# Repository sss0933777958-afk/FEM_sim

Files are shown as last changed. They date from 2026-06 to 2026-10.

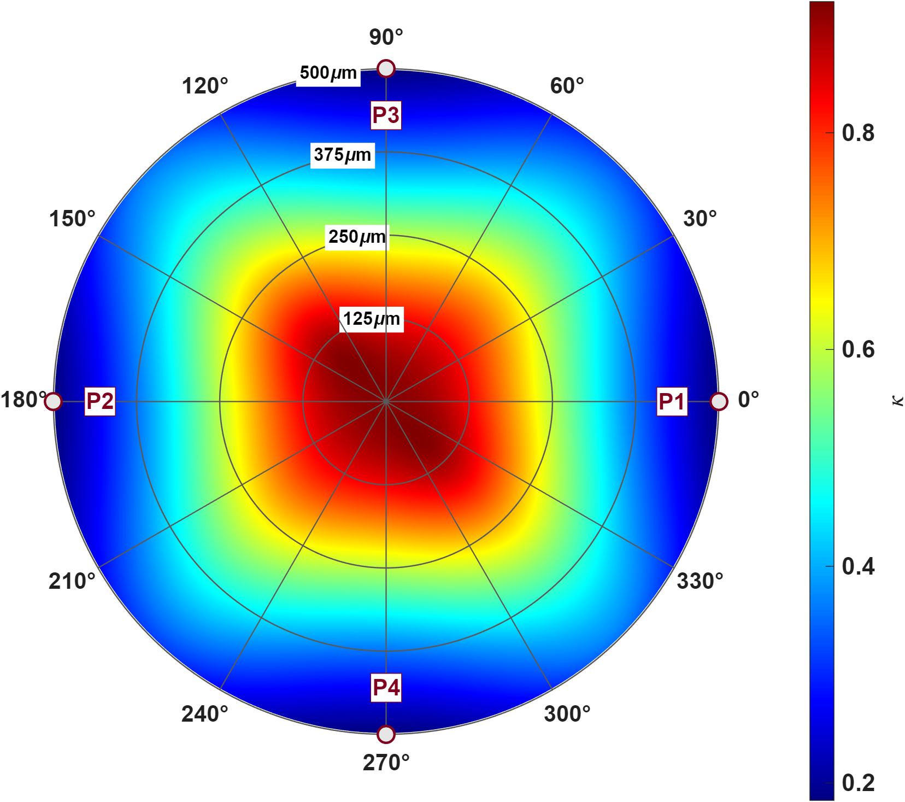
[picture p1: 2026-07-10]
magnetic_sim/ANSYS/main/matlab/Flux/APDL/Calibration_using_FEM_modeling/figures/hung_hexapole/current/common/iso_polar_xaya.png

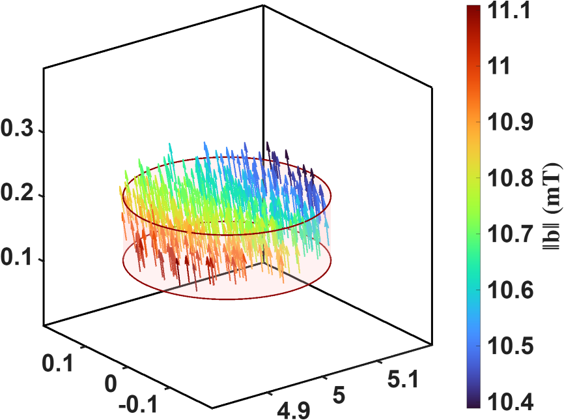
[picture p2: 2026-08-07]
magnetic_sim/ANSYS/main/figures/paper_fig/Section3_A/圖片1.png

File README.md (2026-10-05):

# FEM_sim

六極電磁微探針（hexapole magnetic tweezers）的 FEM 模擬與點磁荷模型校正。

- 求解器：ANSYS MAPDL（APDL）、ANSYS Maxwell
- 分析：MATLAB
- 模型：長飛 2016 半切六極（主力）、志鵬平板六極、hung、NTU

## 資料夾

```
magnetic_sim/ANSYS/
├── main/                    活躍工作區
│   ├── CAD_model/           SolidWorks 原檔 + STEP（幾何的依據）
│   ├── model_check/         交付檢查用的 mm STEP
│   ├── apdl/<model>/        APDL 腳本
│   ├── ANSYS_data/<model>/  APDL 結果（.dat、.db，不進 git）
│   ├── matlab/
│   │   ├── Flux/            磁場模型校正（APDL / Maxwell 兩個分支）
│   │   └── Force/           力模型校正
│   ├── figures/             論文圖
│   └── reference/           推導、報告、論文
└── backup/                  歸檔的舊設計
```

Maxwell 專案與匯出的場（`.fld`）放在 repo 外：`D:\Maxwell_sim\<model>\`。

## 校正包的結構

以 `matlab/Flux/Maxwell/` 為例（Force 沒有自己的 `config/`，共用這裡的）：

| 資料夾 | 放什麼 |
|---|---|
| `config/` | 各模型的設定與幾何 |
| `main/main.m` | 校正主程式，改檔頂的參數切換模型與 current / voltage |
| `function/` | 校正用函式 |
| `data/` | 校正結果 `.mat`（只留定案版） |
| `results/` | 校正結果 PDF |
| `utils/scripts/<model>/`、`utils/data/<model>/` | 額外分析的計算腳本與結果（依模型分夾） |
| `plot/` | 只做繪圖的腳本 |
| `figures/<model>/{current,voltage}/` | 圖 |

## 怎麼跑

```matlab
run('magnetic_sim/ANSYS/main/matlab/Flux/Maxwell/main/main.m')   % 磁場校正
run('magnetic_sim/ANSYS/main/matlab/Force/Maxwell/main/main.m')  % 力模型校正
```

跑完會自動存 `.mat` 到 `data/`、出 PDF 到 `results/`。

## 環境

- ANSYS 2025 R2（MAPDL、Maxwell）
- MATLAB R2025b

## 參考

Fei Long, *Design, Fabrication, and Calibration of a Hexapole Magnetic Tweezers*, PhD Dissertation, Ohio State University, 2016.

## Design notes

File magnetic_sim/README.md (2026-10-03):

# magnetic_sim/ — 磁學模擬類別

**用途**：`FEM_sim/` 下的磁學（magnetostatic / eddy-current）模擬類別，收磁鑷 hexapole / quadrupole 相關工作。目前是 `FEM_sim/` 唯一的物理類別；未來其他 FEM 類別（靜電 / 結構 / 熱）會與本夾**並列**為兄弟資料夾。

**內容**：依**求解器**分子層：
- `ANSYS/` — ANSYS MAPDL 求解器子層（含 `main/` 活躍設計 + `backup/` 歸檔）。
- `COMSOL/` — COMSOL 求解器子層（與 ANSYS/ 並列），目前存 `.mph` 模型。

**相關**：repo 總覽見 `../CLAUDE.md` / `../README.md`；ANSYS 活躍設計導覽見 `../CLAUDE.md`。

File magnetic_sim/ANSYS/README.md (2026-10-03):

# magnetic_sim/ANSYS/ — ANSYS 求解器子層

**用途**：磁學模擬中以 ANSYS MAPDL（APDL magnetostatic FEM）求解的部分。分活躍設計與歸檔兩層。

**內容**：
- `main/` — ★ 目前唯一活躍設計：4-pole MEMS Quadrupole（原 `kuo/`）。完整 pipeline（CAD → IGES → APDL → ANSYS_data → matlab → MATLAB_data → doc）；各子夾有自己的 README。
- `backup/` — 歸檔（非活躍）設計：`hexapole-long2016/`、`hung/`。

**相關**：工作目錄全域規則見 `../../CLAUDE.md`（含資料夾架構地圖 + 產物落點）與 `../../.claude/rules/`；流程 SOP 見 `main/reference/workflows/`；歸檔說明見 `backup/README.md`；COMSOL 部分見 `../COMSOL/README.md`。

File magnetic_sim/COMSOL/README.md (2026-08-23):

# magnetic_sim/COMSOL/ — COMSOL 求解器子層

**用途**：磁學模擬中以 COMSOL Multiphysics 求解的部分，與 `../ANSYS/` 並列為同一磁學類別下的另一求解器。

**內容**：
- `mph/` — COMSOL `.mph` 模型，依 model topic 分子夾（`kuo_quadrupole/`、`long2016_hexapole_halfcut/`）。

**相關**：上層磁學類別見 `../README.md`；COMSOL LiveLink headless 連線通用法見 `../ANSYS/main/reference/workflows/comsol-livelink.md`（拆兩 process + `mphstart(2036)`）；各 model 模型清單見 `mph/README.md`。

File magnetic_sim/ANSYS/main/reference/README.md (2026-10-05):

# reference/ — 文件（LaTeX 推導 / 報告）+ 流程 SOP + 論文 PDF

技術推導、報告 LaTeX 原稿與編譯 PDF，以及 Claude 可 follow 的跨主題流程 SOP。

## 結構
```
reference/
├── workflows/                ← ★ 流程 SOP（cad-export / apdl-fem-run / charge-model-fit / …）
│                               入口見 workflows/README.md
├── Question/                 ← 待討論 / 待辦的研究問題（每題一份 .md）
├── charge_model_fitting/     ← 電荷模型擬合推導（fitting_derivation / general / <model>/）
├── Solve_B_matrix/<model>/   ← B_S 矩陣推導
├── Br_analysis/<model>/      ← Br 分析
├── pole_WP_distance/<model>/ ← pole–WP 距離
├── fitting_trend/scripts/    ← R 掃描趨勢
├── error_definition/{pdf,scripts}
├── magenetic_flux_integral/{pdf,scripts}
└── ur_iteration/{pdf,scripts}
```

## 檔案類型
- `*.tex`（原稿）/ `*.pdf`（編譯產物）/ `*.m`（LaTeX 表格產生器）/ `*.md`（SOP、說明）。

## 規則
- **跑流程 / 操作前先看 `workflows/README.md`** 找對應 SOP（自然語觸發對照也在該 README）。
- LaTeX 原稿放 `<analysis>/<topic>/scripts/`，編譯 PDF 放 `<analysis>/<topic>/pdf/`（analysis-first schema）。
- 中文報告需要圖時 **reference** `../matlab/<model>/<功能組>/figures/<file>.png`，不要把圖另存到 git root 外。

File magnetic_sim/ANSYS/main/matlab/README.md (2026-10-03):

# matlab/ — MATLAB 分析程式碼

讀 FEM 場（APDL `.dat` / Maxwell `.fld`）做點電荷模型擬合、解轉移矩陣、出結果 PDF。

## 第一層 = **求解器分支**（不是 model）

```
matlab/
├── APDL/       ← MAPDL（純量位）求解的場
│   └── Calibration_using_FEM_modeling/   ← 三模型共用校正管線（有自己的 README，權威）
└── Maxwell/    ← Ansys Maxwell 求解的場（結構鏡像上者，但少一層 Calibration 夾）
```

兩分支的 `function/` 是**鏡像**（同檔名、同職責、只差讀檔那一支：`extract_ansys_data` vs
`extract_maxwell_data`）。**改動要兩邊同步**——尤其 `emit_results.m`、`build_V_matrix.m`、
`utils/pole_sensor_geometry.m`。

> 兩分支對同一顆 long2016 模型有 **~14% 的 ĝ_I 落差**（9.66 vs 10.75 mT/A），已排除材料 / 幾何 /
> 安匝 / 網格收斂，尚未結案。比較兩邊數字前先確認基準一致（同 variant、同 R、同 dataset）。

## 共用結構（兩分支皆同）

```
config/<model>/[<geom>/]mt_constants.m   幾何 + 物理常數 + 路由旗標（唯一常數來源）
function/                                管線函式庫（見各分支 function/README.md）
main/main.m                              driver：只改頂部 per-run 旗標
utils/pole_sensor_geometry.m             ★ sensor 貼附幾何**唯一來源**（CAD 實測錐體 + 0.41mm 氣隙）
utils/<model>/                           後處理 compute 腳本（讀 calib .mat → 算 → 存 computed .mat）
plot/<model>/<base>/                     繪圖腳本（讀 .mat → 出圖，不重運算）
data/<model>/.mat/                       所有 .mat（自描述：結果 + 產生它的設定）
results/<model>/{single,eighteen}/        結果 PDF（single=USE_BIAS false、eighteen=true）
figures/<model>/<base>/{single,eighteen,common}/   圖檔
common_path/ansys_path.m                 路徑 resolver（model-agnostic）
```

三段式分工（不可越界）：
**① 校正** `main/main.m` + `function/` → `data/.../calib_*.mat`
→ **② compute** `utils/<model>/` 讀 calib `.mat` → 存 computed `.mat`（**不重跑校正**）
→ **③ 畫圖** `plot/<model>/<base>/` 讀 `.mat` → `figures/`（**不做重運算**）

## 跑法

```matlab
% 改 main.m 頂部旗標即可切換，其餘不用動
MODEL='long2016_hexapole_halfcut'; GEOM='tip40um';
VARIANT='maxwell';        % APDL 分支用 'graded'
BASE='voltage';           % 'current' | 'voltage'
USE_BIAS=true;            % false=single(fix) / true=eighteen(18-param bias)
R_select=150e-6;          % 定案取樣半徑
```
跑完自動存 `.mat` 並呼叫 `emit_results` 出 PDF。

## 產物落點（規則）

- `.mat` → `data/<model>/.mat/`（**不要**再寫 `MATLAB_data/`，該夾 2026-06-26 已移除；
  `matlab_path()` resolver 已 deprecated）。
- PDF → `results/<model>/{single,eighteen}/`，**只放 `.pdf`**（`.tex/.aux/.log` 由 emit 端編完即刪）。
- 圖 → `figures/<model>/<base>/{single,eighteen,common}/`。
- ⚠ **論文圖不在這裡**：`figures/paper_fig_plot/{plot,data}` → `figures/paper_fig/Section*/`。

## 規則（動手前先讀全文）

- **禁止使用 `backup/` 的資料與程式**（`no-backup-data.md`）——常數一律 `model_config(model, geom)`。
- 全程 **actuator frame**（`actuator-frame.md`）、**all-source 號誌**（`charge-model-source-convention.md`）。
- **coil→paper map 是 per-model 不可互抄**（`pole-coil-numbering.md`）；驗證看 K̄_I 對角占優且全正。
- 擬合電流必須 = FEM 激發電流 1 A（`fit-current-matches-sim.md`）。
- 結構凍結：新增 / 改名 / 移動 / 刪除檔或夾**一律先問**（`calibration-shared-structure.md`）。
- 單位：ℓ̂ µm、場 mT、ĝ_I mT/A、ĝ_V mT/mV、V mV（`unit-reference.md`）。

## 相關

`APDL/Calibration_using_FEM_modeling/README.md`（管線總覽）、同夾 `function/README.md`（逐函式速查）、
`../../../../CLAUDE.md`（資料夾架構地圖）、`../ANSYS_data/<model>/RESULTS_MAP.md`（讀結果前必查）。

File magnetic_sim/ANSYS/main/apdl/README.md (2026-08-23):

# apdl/ — APDL 腳本（FEM 的 input）

ANSYS MAPDL 的幾何 / 模擬 / 後處理腳本。這是**重跑 sim 的 input**，改參數/幾何/mesh 都在這裡改。

## 結構：`<model>/{geom,sim,postproc}/`
```
apdl/
├── long2016_hexapole_halfcut/  {geom, sim, postproc}
├── kuo_quadrupole/             {geom, sim, postproc}
└── zhang_quadrupole/           {geom, sim, postproc}
```
- `geom/` — `MT_Geom*.txt` 幾何建模（含 IGES 匯出腳本）。
- `sim/` — `MT_Sim_*.txt` / 各 coil 求解腳本（含 baseline / 變體 / mesh）。
- `postproc/` — 抽場 / dump / PATH 等後處理腳本。

## 檔案類型
- `*.txt` — APDL 腳本（純文字 input）。
- `*.py` — 產生/轉換 APDL 的輔助腳本。

## 規則
- 改動標 `[ADDED]` / `[MODIFIED]`（English comments），見 `.claude/rules/apdl-editing.md`。
- 多 coil 腳本**只差 `CURR_ARRAY`**，其餘同步；`D,ALL,MAG,0` 邊界必存在。
- 改幾何尺寸前對齊 CAD（`ansys-cad-alignment.md`）。
- 跑 FEM / 後處理 SOP：`reference/workflows/{apdl-fem-run,apdl-postproc}.md`。
- 解出來的結果存到 `../ANSYS_data/<model>/<case>/`。

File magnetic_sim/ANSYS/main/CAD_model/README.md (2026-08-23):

# CAD_model/ — SolidWorks / STEP 原始幾何

幾何的 **source of truth**。所有 ANSYS 幾何尺寸必須對齊這裡（見 `.claude/rules/ansys-cad-alignment.md`）。

## 結構：`<topic>/{SLDPRT,STEP}/`

```
CAD_model/
├── kuo_quadrupole/   {SLDPRT, STEP}
├── long_fei/         {SLDPRT, STEP}   ← 注意：此處 topic 名用 long_fei
└── zhang_quadrupole/ {SLDPRT, STEP}
```

> ⚠ 命名不一致：CAD 這裡用 `long_fei`，但 `ANSYS_data/`、`IGES/`、`apdl/` 用 `long2016_hexapole_halfcut`。指同一個物理模型。

## 檔案類型
- `*.SLDPRT` / `*.SLDASM` — SolidWorks 原檔（可編輯的母檔）。
- `*.STEP` — 中性格式匯出（解析尺寸、跨軟體交換）。

## 規則
- 改 ANSYS 幾何 / `mt_constants` 前**必先量對應 CAD**，不一致須通報使用者拍板（per `ansys-cad-alignment.md`）。
- 出 STEP/IGES 流程：`reference/workflows/cad-export.md`。
- STEP 抽參數做參數表：`reference/workflows/step-to-apdl.md`。

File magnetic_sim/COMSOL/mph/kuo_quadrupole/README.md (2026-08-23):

# magnetic_sim/COMSOL/mph/kuo_quadrupole/ — Kuo Quadrupole COMSOL 模型

**用途**：Kuo 4-pole MEMS Quadrupole 的 COMSOL `.mph` 模型（建模迭代 + baseline + 求解版本）。

**內容**（實際 `.mph`）：
- `quadrupole_new.mph` — 目前主用大模型（含解，~360 MB；mphinterp/mpheval 座標用 **mm**，見 memory）。
- `quadrupole_new_split.mph` — 拆分版（精簡）。
- `0.46mm_baseline.mph` — L_P=0.46 mm baseline。
- `tweezer.mph` — 較早的整體 tweezer 模型。
- `monolithic_T55.mph` 及 `quadrupole_*_T55.mph` 系列（imported / with_air / with_coils / with_blocks / with_physics / solved / solved_blocks）— T=55 µm 漸進建模各階段。

**相關**：上層 model 索引見 `../README.md`；LiveLink 連線見 `../../../ANSYS/main/reference/workflows/comsol-livelink.md`；mm 座標探測坑見 memory `feedback_comsol_mm_coord_pitfall`；ANSYS 對應設計見 `../../../ANSYS/main/`。

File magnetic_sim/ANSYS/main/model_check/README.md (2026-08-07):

# model_check/ — 模型檢查交付夾（STEP 主、legacy IGES）

**用途**：ANSYS 建完的幾何**交付使用者疊 CAD/SolidWorks 檢查**的檔案放這裡。
（2026-07-11 由 `IGES_converted/` 改名而來；原「單位轉換後給 ANSYS `IGESIN`」用途已 vestigial——`IGESIN` 2025R2 已棄用，CAD 匯入改走 STEP→SpaceClaim→`ac4para`→`.db`。）

## 🔒 交付一律出 STEP（規則 `deliver-step-for-check.md`）
- **檢查交付檔＝`.step`**（`SI_UNIT(.MILLI.,.METRE.)` 明確 mm，SolidWorks/OCC 讀對）。
- **不要交付 ANSYS `IGESOUT` 的 `.iges`**：被 SolidWorks/OCC **讀成英吋 ×25.4**（板厚 0.25→6.35mm），IGES units flag 6→2 + name `2HMM` **都救不了**。
- STEP 產法：OCC（OCP）讀原始 STEP solid + primitive 實體 compound + `write.step.unit=MM`；範本 `apdl/<model>/geom/scripts/make_*_step.py`。

## 結構：`<model>/`
```
model_check/
├── NTU_hexapole/     pole_assembly.step (交付檢查) + pole*.iges (legacy)
├── long_fei/         *.iges (legacy)
└── hung_hexapole/    *.iges (legacy)
```

## 檔案類型
- `*.step` — **交付檢查用**（mm、SolidWorks 讀對）。
- `*.iges` — legacy（ANSYS IGESOUT 出的、SW 讀成 ×25.4，**勿再交付**，僅留存）。

## 相關
- 規則 `.claude/rules/deliver-step-for-check.md`（交付一律 STEP）。貼 `model_check/<model>/*` 路徑時直接從第二層認模型（`long_fei` / `hung_hexapole` / `NTU_hexapole`），不必問。
- backup/hung 有自己的 `backup/hung/IGES_converted/`（**未改名**，另一設計）。

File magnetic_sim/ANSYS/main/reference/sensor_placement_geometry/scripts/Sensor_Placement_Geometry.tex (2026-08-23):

\documentclass[12pt]{article}
\usepackage[T1]{fontenc}
\usepackage{mathptmx}
\usepackage{amsmath}
\usepackage{amssymb}
\usepackage{array}
\usepackage{booktabs}
\usepackage[a4paper,top=1.6cm,bottom=1.6cm,left=2.3cm,right=2.3cm]{geometry}
\setlength{\parindent}{0pt}
\setlength{\parskip}{4pt}

\newcommand{\ehat}[1]{\mathbf{e}_{#1}}
\newcommand{\rhat}{\hat{\mathbf{r}}}
\newcommand{\that}{\hat{\mathbf{t}}}
\newcommand{\nhat}{\hat{\mathbf{n}}}
\newcommand{\dir}{\operatorname{dir}}

\begin{document}

\begin{center}
\large\textbf{Hall-Sensor Placement Geometry on a Conical Pole}\\[2pt]
\normalsize Derivation of $\;\mathbf{p}=\mathbf{T}+s_{\mathrm{ax}}\ehat{2}+R(s_{\mathrm{ax}})\,\rhat+a\,\ehat{3}$
\end{center}

\vspace{2pt}
\hrule
\vspace{8pt}

\textbf{Scope.} This note derives the closed-form construction used by
\texttt{utils/pole\_sensor\_geometry.m}, which is the single source of truth for the
six Hall-sensor centres $\mathbf{p}_i$ and their outward normals $\nhat_i^{+}$.
All vectors are expressed in the WP frame (origin at the common sphere centre of the
six pole tips) in metres. The construction is per-pole; the index $i$ is dropped.

\section{Direction convention}

Every direction below is written with the elevation--azimuth helper
\begin{equation}
\dir(\varepsilon,\theta)=
\begin{bmatrix}\cos\varepsilon\cos\theta\\ \cos\varepsilon\sin\theta\\ \sin\varepsilon\end{bmatrix},
\qquad
\dir(\varepsilon,\theta)\cdot\dir(\varepsilon',\theta)=\cos(\varepsilon-\varepsilon').
\label{eq:dir}
\end{equation}
The second identity is the only algebra needed to check orthogonality inside a
meridian plane: two directions sharing the azimuth $\theta$ are orthogonal iff their
elevations differ by $90^\circ$.

Per-pole inputs: azimuth $\theta$ (pole angles $0,180,120,300,60,240^\circ$ for
$P_1\ldots P_6$) and the layer flag (lower / upper).

\section{Pole tip and pole axis}

\textbf{Tip.} The six tips lie on a sphere of radius $\ell=R_{\mathrm{norm}}$. The
magic-angle elevation follows from the locked hexapole constraints
$R_{\mathrm{norm},xy}=\ell\sqrt{2/3}$, $R_{\mathrm{norm},z}=\ell/\sqrt{3}$:
\begin{equation}
\psi_0=\arctan\!\frac{R_{\mathrm{norm},z}}{R_{\mathrm{norm},xy}}
      =\arctan\frac{1}{\sqrt2}=35.2644^\circ ,
\qquad
\ehat{1}=\dir\!\big(\sigma_\ell\psi_0,\ \theta\big),\qquad
\mathbf{T}=\ell\,\ehat{1},
\label{eq:tip}
\end{equation}
with $\sigma_\ell=-1$ for a lower pole and $+1$ for an upper pole.

\textbf{Axis.} The cone axis $\ehat{2}$ points from the tip \emph{towards the base}
(direction of increasing axial station $s$):
\begin{equation}
\ehat{2}=\dir(\varepsilon,\theta),\qquad
\varepsilon=\begin{cases}
0 & \text{lower pole (horizontal axis)}\\
\varepsilon_{\mathrm{up}}=36.5895^\circ & \text{upper pole}.
\end{cases}
\label{eq:axis}
\end{equation}

\textbf{Remark (do not confuse $\ehat{1}$ with $\ehat{2}$).} The tip direction and the
pole axis are \emph{different} vectors. For a lower pole $\ehat{1}$ has elevation
$-35.2644^\circ$ while $\ehat{2}$ is horizontal; for an upper pole the elevations are
$+35.2644^\circ$ and $+36.5895^\circ$. Only $\ehat{1}$ carries the magic angle --- it is
fixed by the orthogonality/common-sphere constraints. The axis inclination
$\varepsilon_{\mathrm{up}}$ is the physical tilt of the machined pole and is an
independent number.

\section{The local triad and the radial vector \boldmath$\rhat$}

This is the part that is easy to forget. Fix a pole. Two more unit vectors are built
so that $\{\ehat{2},\rhat_0,\that\}$ is orthonormal:
\begin{align}
\rhat_0 &= \dir\!\big(\varepsilon+\sigma\,90^\circ,\ \theta\big),
  &&\sigma=\begin{cases}-1 & \text{lower pole}\\ +1 & \text{upper pole}\end{cases}
  \label{eq:rad0}\\[2pt]
\that &= \begin{bmatrix}-\sin\theta\\ \cos\theta\\ 0\end{bmatrix}.
  \label{eq:tanv}
\end{align}

\textbf{Why these are orthonormal.} $\ehat{2}$ and $\rhat_0$ share the azimuth
$\theta$ and their elevations differ by exactly $90^\circ$, so
$\ehat{2}\cdot\rhat_0=\cos(\mp90^\circ)=0$ by \eqref{eq:dir}. The vector $\that$ is
horizontal and perpendicular to the azimuthal direction
$[\cos\theta,\sin\theta,0]^{\mathsf T}$, hence perpendicular to \emph{any}
$\dir(\cdot,\theta)$; in particular $\that\perp\ehat{2}$ and $\that\perp\rhat_0$.

\textbf{Geometric meaning.}
\begin{itemize}\itemsep2pt
\item $\ehat{2},\rhat_0$ span the \emph{meridian plane} --- the vertical plane
      containing the pole axis (azimuth $\theta$). $\rhat_0$ is the radial direction
      inside that plane, pointing away from the axis.
\item The sign $\sigma$ selects \emph{which side} of the axis the sensor is mounted on.
      A lower pole is the half-cut part: the mounting face is its \textbf{bottom} cone
      surface, so $\sigma=-1$ tilts $\rhat_0$ downwards. An upper pole is a full cone
      and is mounted on the upper side, so $\sigma=+1$.
\item $\that$ is tangential --- perpendicular to the meridian plane. It is only needed
      to rotate the mounting point around the pole axis.
\end{itemize}

\textbf{Azimuthal placement around the axis.} Rotating $\rhat_0$ about $\ehat{2}$ by an
angle $\psi$ stays in the plane spanned by $\rhat_0$ and $\that$ (both are
perpendicular to $\ehat{2}$), so Rodrigues' formula collapses to
\begin{equation}
\boxed{\ \rhat(\psi)=\cos\psi\;\rhat_0+\sin\psi\;\that\ }
\label{eq:rhat}
\end{equation}
with $\rhat(\psi)\perp\ehat{2}$ and $\|\rhat(\psi)\|=1$ for all $\psi$. The canonical
sensor azimuth is $\psi=0$, i.e. $\rhat=\rhat_0$, which places the sensor in the
meridian plane --- directly below (lower) or above (upper) the pole axis.

\textbf{Caveat on the sense of rotation.} A direct evaluation of the cross product
gives $\ehat{2}\times\rhat_0=-\sigma\,\that$. Therefore \eqref{eq:rhat} is a
right-handed rotation about $\ehat{2}$ by $-\sigma\psi$: the sense of increasing $\psi$
is opposite between the two layers. This is immaterial at the default $\psi=0$ and for
symmetric sweeps, but it must be kept in mind if a signed azimuthal offset is ever
imposed.

\section{The real cone: virtual apex, radius, and outward normal}

\subsection{Virtual apex}

The pole is not a mathematically sharp cone: the tip is rounded with a fillet of
radius $r_f=40\ \mu$m, and the conical surface is \emph{tangent} to that sphere. Let
$\beta$ be the true half-cone angle. For a sphere of radius $r_f$ inscribed tangentially
in a cone of half-angle $\beta$, the distance from the apex to the sphere centre is
$r_f/\sin\beta$. Placing the sphere centre at axial station $s=r_f$ (so that the
foremost point of the sphere --- the physical tip $\mathbf{T}$ --- sits at $s=0$), the
apex lies \emph{outside} the material at
\begin{equation}
s=-e_v,\qquad
\boxed{\ e_v=\frac{r_f}{\sin\beta}-r_f\ }\;\approx\;0.16\ \mathrm{mm}.
\label{eq:apex}
\end{equation}

\subsection{Cone radius}

Measuring the axial station $s$ from the physical tip, the distance from the virtual
apex is $e_v+s$, so
\begin{equation}
R(s)=(e_v+s)\tan\beta,
\qquad
R(0)=e_v\tan\beta\approx 0.033\ \mathrm{mm}\neq 0 .
\label{eq:radius}
\end{equation}
The non-zero intercept is the whole point: \textbf{at the axial position of the tip the
cone surface already has a finite radius}. Anchoring the mounting point at the ideal
tip with $R=0$ is what used to push the sensor into the steel (Sec.~\ref{sec:old}).

\subsection{Outward normal}

Parametrise the cone surface by $(s,\psi)$:
\begin{equation}
\mathbf{P}(s,\psi)=\mathbf{T}+s\,\ehat{2}+R(s)\,\rhat(\psi).
\end{equation}
The generator (slant) direction is
\begin{equation}
\hat{\mathbf{g}}
=\frac{\partial\mathbf{P}/\partial s}{\|\partial\mathbf{P}/\partial s\|}
=\frac{\ehat{2}+\tan\beta\,\rhat}{\sqrt{1+\tan^2\beta}}
=\cos\beta\,\ehat{2}+\sin\beta\,\rhat .
\label{eq:gen}
\end{equation}
The surface normal lies in the meridian-like plane $\mathrm{span}\{\ehat{2},\rhat\}$,
is perpendicular to $\hat{\mathbf{g}}$, and must point away from the axis
($\nhat\cdot\rhat>0$). The unique unit vector satisfying all three is
\begin{equation}
\boxed{\ \ehat{3}\;=\;\nhat^{+}\;=\;\cos\beta\,\rhat-\sin\beta\,\ehat{2}\ }
\label{eq:normal}
\end{equation}
since $\hat{\mathbf{g}}\cdot\ehat{3}=\cos\beta\sin\beta-\sin\beta\cos\beta=0$ and
$\ehat{3}\cdot\rhat=\cos\beta>0$. At $\psi=0$ this is exactly
$\dir\!\big(\varepsilon+\sigma(\beta+90^\circ),\theta\big)$, i.e. the axis direction
rotated by $\sigma(90^\circ+\beta)$ inside the meridian plane.

\section{Axial station from the slant offset}

$\mathrm{SOFF}$ is defined as the \textbf{slant distance measured along the generator},
starting from the ``red point'' --- the point of the generator at the same axial station
as the tip, i.e. $(s,R)=(0,\,e_v\tan\beta)$. Advancing a slant distance
$\mathrm{SOFF}$ along $\hat{\mathbf{g}}$ advances the axial station by its $\ehat{2}$
component, hence
\begin{equation}
\boxed{\ s_{\mathrm{ax}}=\mathrm{SOFF}\cdot\cos\beta\ }
\label{eq:sax}
\end{equation}
with the design value $\mathrm{SOFF}=4.572$~mm ($=0.18$~inch).

\textbf{Convention.} Quoting a mounting offset always means the \emph{full} slant
distance measured in the meridian plane, \emph{including} its leading segment: saying
``$\mathrm{SOFF}=4$~mm'' already contains the portion $t_{\tan}$ that is pressed
against the fillet rather than the cone, and the whole $4$~mm is then projected onto
the axis by $\cos\beta$. The CAD-measured fillet segments are $t_{\tan}=0.0328$~mm
(lower) and $0.0311$~mm (upper); they are recorded only for drawing the pole outline
and do \emph{not} enter \eqref{eq:sax}.

\textbf{History.} An earlier revision used
$s_{\mathrm{ax}}=(\mathrm{SOFF}-t_{\tan})\cos\beta+t_{\tan}$, which measured
$\mathrm{SOFF}$ from the physical tip and treated the leading segment as purely
axial. The two differ by $t_{\tan}(1-\cos\beta)\approx0.6\ \mu$m, three orders of
magnitude below the air gap, so no downstream result changed.

\section{Assembly}

Stacking \eqref{eq:tip}, \eqref{eq:sax}, \eqref{eq:radius}, \eqref{eq:rhat} and
\eqref{eq:normal}, and lifting the sensor off the surface by the air gap
$a=0.41$~mm along the outward normal:
\begin{equation}
\boxed{\;
\mathbf{p}
=\underbrace{\mathbf{T}}_{\text{tip}}
+\underbrace{s_{\mathrm{ax}}\,\ehat{2}}_{\text{slide along axis}}
+\underbrace{R(s_{\mathrm{ax}})\,\rhat(\psi)}_{\text{out to the cone surface}}
+\underbrace{a\,\ehat{3}}_{\text{lift off the surface}}\;}
\label{eq:assembly}
\end{equation}

Read left to right, the four terms are: start at the pole tip; slide along the axis to
the correct axial station; step radially outwards until you reach the actual cone
surface at that station; then lift perpendicular to that surface by the air gap.
Because the last step uses the true surface normal \eqref{eq:normal}, the perpendicular
distance from the sensor centre to the cone surface is \emph{exactly} $a$ by
construction.

\subsection*{Degenerate case: flat mounting face}

For the lower pole the option \texttt{face\_lower='flat'} mounts the sensor on the
half-cut plane instead of the bottom cone. That plane \emph{contains} the pole axis,
so there is no radial stand-off and no slant projection:
\begin{equation}
s_{\mathrm{ax}}=\mathrm{SOFF},\qquad R=0,\qquad \nhat^{+}=\hat{\mathbf{z}},
\qquad \mathbf{p}=\mathbf{T}+\mathrm{SOFF}\,\ehat{2}+a\,\hat{\mathbf{z}} .
\end{equation}
The azimuth $\psi$ has no meaning for a plane and is ignored.

\section{Numerical values (long2016 half-cut, CAD-measured cone)}
\label{sec:num}

$\ell=0.5$~mm, $r_f=0.04$~mm, $\mathrm{SOFF}=4.572$~mm, $a=0.41$~mm.
The two layers have \emph{different} measured cone slopes
($\tan\beta=0.20330$ lower, $0.19463$ upper; a $4.4\%$ difference).

\begin{center}
\begin{tabular}{lccccc}
\toprule
Layer & $\beta$ [deg] & $e_v$ [mm] & $s_{\mathrm{ax}}$ [mm] & $R(s_{\mathrm{ax}})$ [mm] & poles \\
\midrule
Lower & 11.4916 & 0.16078 & 4.48035 & 0.94354 & $P_1,P_3,P_6$ \\
Upper & 11.0138 & 0.16937 & 4.48779 & 0.90642 & $P_2,P_4,P_5$ \\
\bottomrule
\end{tabular}
\end{center}

Spot check for $P_1$ ($\theta=0$, lower, $\psi=0$): $\ehat{2}=[1,0,0]^{\mathsf T}$,
$\rhat_0=\dir(-90^\circ,0)=[0,0,-1]^{\mathsf T}$, so \eqref{eq:normal} gives
\[
\nhat^{+}=\cos\beta\,[0,0,-1]^{\mathsf T}-\sin\beta\,[1,0,0]^{\mathsf T}
=[-0.1992,\ 0,\ -0.9800]^{\mathsf T},
\]
which is what the code returns. The normal tilts $\beta$ away from straight-down,
as it must for a surface whose generator is inclined by $\beta$ to the axis.

\section{Why the naive construction fails}
\label{sec:old}

A tempting shortcut is to anchor at the ideal tip and walk the slant distance directly:
$\mathbf{p}=\mathbf{T}+\mathrm{SOFF}\cdot\dir(\varepsilon+\sigma\beta,\theta)+a\,\ehat{3}$.
This ignores the finite radius $R(0)=e_v\tan\beta\approx0.033$~mm at the tip station,
so the mounting point is placed \emph{inside} the steel. The resulting perpendicular
distance to the \emph{real} cone surface is
\[
0.3635\ \mathrm{mm}\ \text{(lower)},\qquad 0.4012\ \mathrm{mm}\ \text{(upper)},
\]
instead of the specified $0.41$~mm --- an $11\%$ error on the lower poles, and
inconsistent between layers. The construction \eqref{eq:assembly} removes both defects:
the stand-off is exactly $a$ on every pole.

\vspace{6pt}
\hrule
\vspace{4pt}
{\footnotesize
\textbf{Implementation:} \texttt{matlab/Maxwell/utils/pole\_sensor\_geometry.m}
(and the identical copy under \texttt{matlab/APDL/Calibration\_using\_FEM\_modeling/utils/}).
Consumers: \texttt{build\_V\_matrix.m} and every script that draws sensors or pole
outlines --- none of them may re-derive this geometry locally.\par
\textbf{Related:} \texttt{.claude/rules/ansys-cad-alignment.md} (CAD is the source of
truth); memory \texttt{long2016-pole-cone-geometry} (STEP measurements and how they
were taken).}

\end{document}

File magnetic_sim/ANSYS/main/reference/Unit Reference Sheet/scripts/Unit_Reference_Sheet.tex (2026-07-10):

\documentclass[12pt]{article}
\usepackage[T1]{fontenc}
\usepackage{mathptmx}
\usepackage{amsmath}
\usepackage{amssymb}
\usepackage{array}
\usepackage[a4paper,top=1.5cm,bottom=1.5cm,left=2.3cm,right=2.3cm]{geometry}
\setlength{\parindent}{0pt}

\begin{document}

\begin{center}
\large\textbf{Lumped-Parameter Modeling and Calibration of Hexapole\\
Electromagnetic Actuators for Magnetic Flux Generation}
\end{center}

\vspace{6pt}

\textbf{Current Base Model}
\[
b(p) = \underbrace{\left(\tfrac{6}{5}k_{11}\right)\left(\frac{N_c}{4\pi\,\widehat{\ell}^{\,2}\,R_a}\right)}_{\textstyle {}^{B}\widehat{g}_{I}}\; S_i\,\overline{K}_{I}\,I
= S_i\Big(\underbrace{{}^{B}\widehat{g}_{I}\,\overline{K}_{I}\,I}_{\textstyle G}\Big)
\]

\vspace{10pt}

\textbf{Voltage Base Model}
\[
b(p) = S_i\cdot D\cdot V
= S_i\cdot\Big[\underbrace{\left(\tfrac{6\,d_{11}}{5}\right)}_{\textstyle {}^{B}\widehat{g}_{V}}\overline{D}\,V\Big]
= S_i\Big(\underbrace{{}^{B}\widehat{g}_{V}\,\overline{D}\,V}_{\textstyle G}\Big)
\]

\vspace{8pt}

\begin{center}
\renewcommand{\arraystretch}{2.6}
\begin{tabular}{>{\centering\arraybackslash}m{6.0cm} | >{\centering\arraybackslash}m{4.5cm}}
\multicolumn{1}{c|}{\textbf{Symbol}} & \multicolumn{1}{c}{\textbf{Unit}} \\[2pt]
\hline
$R_a$ & $\dfrac{A}{Wb}$ \\
\hline
$I$ & $A$ \\
\hline
${}^{B}\widehat{g}_{I}$ & $\dfrac{mT}{A}$ \\
\hline
${}^{B}\widehat{g}_{V}$ & $\dfrac{mT}{mV}$ \\
\hline
$V$ & $mV$ \\
\hline
$\widehat{\ell}$ & $\mu m$ \\
\hline
$b(p)$ & $mT$ \\
\hline
$\left(\dfrac{3V}{\mu_0}\right)\!\left(\dfrac{\mu-\mu_0}{\mu+2\mu_0}\right) \triangleq {}^{M}\widehat{g}_{B}$ & $\dfrac{\mathbf{m}}{mT}$ \\
\hline
$\left(\dfrac{{}^{M}\widehat{g}_{B}}{2\widehat{\ell}}\right)\!\left({}^{B}\widehat{g}_{I}\right)^{2} \triangleq {}^{F}\widehat{g}_{I}$ & $\dfrac{pN}{A^{2}}$ \\
\hline
$\left(\dfrac{{}^{M}\widehat{g}_{B}}{2\widehat{\ell}}\right)\!\left({}^{B}\widehat{g}_{V}\right)^{2} \triangleq {}^{F}\widehat{g}_{V}$ & $\dfrac{pN}{mV^{2}}$ \\
\hline
$\mathbf{m}(p) \triangleq {}^{M}\widehat{g}_{B}\cdot b(p)$ & $A\cdot \mu m^{2}$ \\
\hline
$\begin{cases} k_m = \dfrac{\mu_0}{4\pi} = 10^{-7} \\[6pt] \mu_0 = 4\pi\cdot 10^{-7} = 0.0013\cdot 10^{-3} \end{cases}$ & $\dfrac{pN}{A^{2}}$ \\
\hline
\end{tabular}
\end{center}

\end{document}

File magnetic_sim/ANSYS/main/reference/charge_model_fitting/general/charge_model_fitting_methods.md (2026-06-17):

# 磁荷模型擬合：三種方法詳解 [A] / [J] / [B-6x]

> **文件目的**：詳細寫出 Long Fei dissertation Section 2.2.3 「6-charge magnetic field model」三種等級擬合方法的**完整推導過程 + 演算法步驟 + MATLAB code + 數值範例**。
>
> **適用對象**：要重做 fit、要 reproduce 結果、要寫論文 methodology 章節的人。
>
> **最後更新**：2026-06-03

---

## 目錄

- [0. 為什麼要 fit + 龍飛 b=0 假設](#0-為什麼要-fit-磁荷模型)
- [1. 三方法共用的數學工具與資料前處理](#1-三方法共用基礎)
- [2. Method [A] — 共用 ell 球面擬合（2 參數）](#2-method-a--共用-ell-球面擬合2-參數)
- [3. Method [J] — 6-coil joint 自由 3D 擬合（24 參數）](#3-method-j--6-coil-joint-自由-3d-擬合24-參數)
- [4. Method [B-6x] — ell+δ 全激勵擬合（19 參數）★ 定案](#4-method-b-6x--ellδ-全激勵擬合19-參數--定案)
- [5. 三方法對比與何時用哪個](#5-三方法對比)
- [6. 對龍飛 b=0 假設的回饋](#6-對龍飛-b0-假設的回饋)
- [7. 腳本/數據/圖檔清單](#7-腳本資料圖檔清單)
- [8. 名詞速查](#8-名詞速查)

---

## 0. 為什麼要 fit 磁荷模型？

### 0.1 出發點

Long Fei dissertation Eq 2.2 把 6 顆 pole 的 B 場 model 寫成 6 個**等效點電荷** (point charges)：

```
        ⎛   6                                     ⎞
B(p) = ⎜  Σ   k_m · q_i / |p − c_i|² · u_i(p, c_i) ⎟
        ⎝ i=1                                     ⎠
```

其中：
- `q_i` = 第 i 顆 pole 的等效磁荷（[A·m]）
- `c_i` = 第 i 顆磁荷的位置（[m]）
- `k_m = μ₀/(4π) = 10⁻⁷ N/A²`

每顆 charge 有 1 個 **scalar** 強度 q_i 跟 3 個 **位置** (x_i, y_i, z_i)。總計 6×4 = 24 自由度。

### 0.2 龍飛的兩個 fit 假設

論文 page 18-20 fit 出 (ρ, R_a) = (900 µm, 6.3×10⁸ A/Wb)。
他**暗藏**兩個假設：

1. **位置假設**：所有 charge 都坐在半徑 ρ 的球面上，方位由 pole tip 幾何決定 → **b_i ≡ 0**（每顆 charge 沒有額外偏移）
2. **強度假設**：6 顆 charge 強度由 K_I 矩陣 + R_a 決定，**只剩 R_a 是 free 參數**

→ 自由度從原本 24 砍到剩 **2** (ρ, R_a)。

### 0.3 三種方法的定位

我們做的三種 fit 是 **逐步放鬆龍飛的兩個假設**：

| Method | 自由度 | 放鬆什麼 | 數據量 | 主要目的 |
|---|---|---|---|---|
| **[A]** | **2** | 完全照龍飛 (b=0 + 球面) | 1 coil (P1) | reproduce Long Fei，提供 ρ baseline |
| **[J]** | **24** | 放開到全自由 (18 dim bias + 6 個獨立 C) | 6 coils | 量化 b≠0 偏離有多大 |
| **[B-6x]** | **19** | ρ 鎖定 + 自由 δ + 共用 1 個 C ★定案 | all6 superposition | 物理上最一致 + 數值最準 |

下面三章逐一**完整**推導。

---

## 1. 三方法共用基礎

### 1.1 統一的 fit 方程（被擬合的物理 model）

**從 Long Fei Eq 2.1-2.4 一路推到 fit 用的形式**：

#### Step A：原始物理 model（Eq 2.2）

```
            6                  p − c_i
B(p) =  Σ   k_m · q_i · ──────────────────
           i=1            |p − c_i|³
```

- **k_m = μ₀/(4π) = 10⁻⁷ N/A²**（磁 Coulomb 常數，跟靜電 Coulomb 1/(4πε₀) 對應）
- q_i = 第 i 顆 charge 強度 [A·m]

#### Step B：把電流→磁荷（Eq 2.1 + 2.4）

```
q_i = Φ_i / μ₀ = -(N_c / (μ₀ · R_a)) · (K_I · I_vec)_i = -(N_c/(μ₀·R_a)) · w_i
```

代回 Step A：

```
            ⎛   N_c       ⎞   6                p − c_i
B(p) = -k_m·⎜ ──────────  ⎟ · Σ   w_i · ──────────────────
            ⎝ μ₀ · R_a   ⎠  i=1          |p − c_i|³
       └──────────────────┘
       這整坨叫做「振幅 ξ」
```

#### Step C：合併成 fit-friendly 形式

```
            ⎛  6                p − c_i             ⎞
B_model(p; θ) = ξ · ⎜  Σ   w_i · ──────────────────  ⎟       ← fit 用形式
            ⎝ i=1               |p − c_i|³             ⎠

其中  ξ = -k_m · N_c / (μ₀ · R_a)
     = 振幅因子（合併 k_m 跟所有物理常數）
```

| 變數 | 意義 | 在三方法中的角色 |
|---|---|---|
| **ξ** | 全局振幅 = -k_m · N_c/(μ₀·R_a) | 解析解（VarPro），所有方法都這樣處理 |
| **k_m** | 磁 Coulomb 常數 = μ₀/(4π) = 10⁻⁷ N/A² | 物理常數，吸收進 ξ |
| **N_c** | 每極線圈匝數 = 70 | 物理常數，吸收進 ξ |
| **μ₀** | 真空磁導率 = 4π×10⁻⁷ T·m/A | 物理常數 |
| **R_a** | 集總空氣磁阻 [A/Wb] | 唯一 free 物理量，從 ξ 反推 |
| **w_i** | 第 i 顆 charge 的相對權重 = (K_I · I_vec)_i | 固定（由激勵電流決定） |
| **c_i** | 第 i 顆 charge 的 3D 位置 | **三方法差別就在這怎麼參數化** |
| **p** | 場點位置 [m] | FEM 節點座標 |

#### Step D：從 ξ 反推 R_a

fit 完拿到 ξ 後：

```
            k_m · N_c
R_a = ─────────────────────
          μ₀ · |ξ|
```

（負號 cancel；取 |ξ| 是因為 SOURC36 繞線方向給的符號 convention，per `coil_sign`）

> **注意**：在 MATLAB code 裡（per `point_charge_model.m`），習慣把 ξ 拆成兩部分：
> - 「外層 C」= N_c/(μ₀·R_a) ← 對應 `R_a_unit = N_c/μ₀` 讓 C=1 的 trick
> - 「內層 k_m」 baked into b_unit（因為 `point_charge_model` 函式內部已乘 k_m）
> 兩種 convention 數學等價，本文檔之後用 ξ 統一表示「整坨振幅」。

### 1.2 統一的 cost function

```
              N    
J(θ) = Σ Σ  ‖ B_model(p_j; θ) − B_FEM(p_j) ‖²       ← 向量 L² norm
        j=1
              ↑                ↑
       647 個 FEM 節點    對應 3 個分量 (Bx, By, Bz)
```

→ residual 是 **3N = 1941 維向量**（647 node × 3 component），用 `fminsearch` / `fminbnd` 最小化。

### 1.3 Variable Projection (VarPro) — 把 ξ 消掉

關鍵觀察：**B_model 對 ξ 是線性**（位置決定方向，ξ 只是振幅）。

定義 `b_geom(θ_geom) = Σᵢ wᵢ · (p − cᵢ)/|p − cᵢ|³`（純幾何 basis，不含 k_m 或 R_a）：

```
B_model(p; θ) = ξ · b_geom(p; θ_geom)

J(ξ, θ_geom) = ‖ ξ · b_geom(θ_geom) − b_FEM ‖²
```

對 ξ 求導 = 0 解析：

```
            b_geom^T · b_FEM
ξ_opt = ─────────────────────
            b_geom^T · b_geom
```

→ **不用數值搜尋 ξ**，每次只搜尋 θ_geom，每個 θ_geom 都直接代公式算 ξ_opt。Reduced cost：

```
                            (b_geom^T · b_FEM)²
J*(θ_geom) = ‖b_FEM‖² −  ─────────────────────
                              b_geom^T · b_geom
```

從 ξ_opt 回推 R_a：

```
R_a = k_m · N_c / (μ₀ · |ξ_opt|)
```

**Method [A] / [J] / [B-6x] 都用這個 trick**。
（在 code 裡 b_unit 已含 k_m，所以分兩階段：先算 C_opt 再算 R_a，數學等價於這裡的 ξ_opt。）

### 1.4 K_I 磁通分佈矩陣

當激勵 Coil k（i.e., 通 1A 到 pole k 的線圈），6 顆 charge 的權重：

```
w = K_I · I_vec,    K_I = I₆ − (1/6) · 1₆ = ⎡ 5/6  −1/6  ⋯  −1/6 ⎤
                                              ⎢ ⋮              ⋮  ⎥
                                              ⎣ −1/6 ⋯       5/6 ⎦
```

例：激勵 P1 (`I_vec = [1,0,0,0,0,0]ᵀ`) → `w = [5/6, −1/6, −1/6, −1/6, −1/6, −1/6]ᵀ`

- 主極 P1 得 **5/6** 權重（dominant、flux sink）
- 其餘 5 顆各得 **−1/6**（passive、flux source）
- 總和 = 0（磁通守恆，div B = 0）

### 1.5 資料前處理鏈（共用）

```
ANSYS FEM (V4 halfcut baseline, 6 coils × 0.6A) 
    ↓ 載入 coord + bfield .dat → 390k nodes
    ↓ 鐵芯節點排除 (geometric cone filter) → 341k nodes
    ↓ 取 WP 中心 100 µm cube |x|,|y|,|z_wp| < 50 µm → 647 nodes
    ↓ 座標轉換 z_wp = z_apdl − SPH_OFST (SPH_OFST = −12.711 mm)
    ↓ B 場分量堆疊
b_FEM = [bx; by; bz] (1941 × 1)
```

### 1.6 物理常數 + 幾何常數（從 `mt_constants.m`）

**物理常數**：

| 符號 | 數值 | 意義 |
|---|---|---|
| **μ₀** | 4π×10⁻⁷ T·m/A | 真空磁導率 |
| **k_m** | μ₀/(4π) = **10⁻⁷ N/A²** | 磁 Coulomb 常數（dissertation page 18 標 `km = μ₀ = 1.0×10⁻⁷ N/A²`，跟 `μ₀/4π` 等價）|
| **N_c** | 70 | 每極線圈匝數（dissertation page 14）|

**幾何常數**：

```
R_norm    = 500 µm           WP 到極尖物理距離
R_norm_xy = R_norm·√(2/3) = 408 µm
R_norm_z  = R_norm/√3 = 289 µm
α         = arctan √2 = 54.74°   極角
SPH_OFST  = −12.711 mm        APDL → WP 座標 z 平移
```

6 極方位角 (paper 索引)：
- Lower (P1, P3, P6): θ = 0°, 120°, 240°，z_sign = −1
- Upper (P2, P4, P5): θ = 180°, 300°, 60°，z_sign = +1

APDL index → paper index 映射：APDL `{1,2,3,4,5,6}` = Paper `{P1, P3, P6, P5, P2, P4}`。

---

## 2. Method [A] — 共用 ell 球面擬合（2 參數）

**腳本**：`magnetic_sim/ANSYS/backup/hexapole-long2016/analysis/fit_charge_model.m`
**輸出**：`data/charge_model_fit.mat`
**主結果**：ell = 835.4 µm, R_a = 9.21×10⁸ A/Wb, mean err 4.94%

### 2.1 假設（完全照搬龍飛）

- 6 顆 charge 全部坐在半徑 ell 的球面上
- 方位由 pole tip 幾何完全鎖死
- 6 顆共用同一個 ell
- 共用同一個 R_a（即同一個 C）
- 只用 1 個 coil (P1, APDL coil 1) 的數據

### 2.2 數學參數化

charge 位置：

```
c_i = ell · d̂_i,   i = 1..6

d̂_i = [cos θ_i · sin α,  sin θ_i · sin α,  z_sign_i · cos α]
```

α = 54.74° 固定。θ_i 跟 z_sign_i 由 paper 幾何完全決定。

驗證：|c_i| = ell·√(sin²α + cos²α) = ell ✓

**自由變數總計 = 2 個**：
- ell ∈ [400, 2000] µm（位置，數值搜尋）
- C → R_a（VarPro 解析）

### 2.3 演算法詳細步驟

```
Step 0: 載入資料
    d = import_ansys_data('coil1', 'all', 'coil1')
    把 (x, y, z) 轉到 WP 座標系: z_wp = z − SPH_OFST
    應用鐵芯過濾 → 341k nodes
    取 100 µm cube → 647 nodes
    b_FEM = [bx; by; bz]   ← 1941×1

Step 1: 設定 K_I 跟 I_vec
    K_I = I₆ − (1/6)·1₆
    APDL coil 1 → paper P1, 所以 I_vec = [1, 0, 0, 0, 0, 0]ᵀ (paper 順序)
    w = K_I · I_vec = [5/6, −1/6, −1/6, −1/6, −1/6, −1/6]ᵀ
    
    coil_sign = +1 (P1 是 lower, SOURC36 繞線方向給 sink)

Step 2: Phase 1 — ell 粗掃
    For ell ∈ linspace(400e-6, 2000e-6, 300):
        c_i = ell · d̂_i,  i = 1..6
        對每個 FEM 節點 p_j 算 b_unit_j = Σᵢ w_i · (p_j − c_i)/|p_j − c_i|³
        b_unit_vec = [b_unit_x; b_unit_y; b_unit_z]  ← 1941×1
        C_opt(ell) = (b_unit_vec' · b_FEM) / (b_unit_vec' · b_unit_vec)
        cost(ell) = ‖ C_opt · b_unit_vec − b_FEM ‖²
    
    ell_0 = argmin cost(ell)

Step 3: Phase 2 — fminbnd 精煉
    ell* = fminbnd(@(ell) ell_cost(ell, p_FEM, b_FEM, w),
                   ell_0 − 200e-6, ell_0 + 200e-6,
                   optimset('TolX', 1e-12))

Step 4: 取最後 C_opt 並回推 R_a
    [b_unit*, ~] = compute_unit_field(ell*, w, p_FEM)
    C_opt* = (b_unit*' · b_FEM) / (b_unit*' · b_unit*)
    R_a = N_c / (μ₀ · |C_opt*|)
    
Step 5: 報告誤差
    B_pred = C_opt* · b_unit*
    residual = B_pred − b_FEM
    err_per_node = ‖residual_j‖ / ‖B_FEM_j‖    對每個節點
    mean_err = mean(err_per_node)
    max_err = max(err_per_node)
```

### 2.4 MATLAB code 骨架

```matlab
% --- fit_ell_cost.m (核心 cost function) ---
function [cost, C_opt] = fit_ell_cost(ell, p_wp, b_fem, w, K_I, c)
    % Build 6 charge positions
    d_hat = build_d_hat(c);              % 6×3 方向矩陣
    charges = ell * d_hat;               % 6×3 位置矩陣
    
    % Build unit field
    R_a_unit = c.N_c / c.mu_0;           % 讓 C=1
    [bx, by, bz] = point_charge_model(p_wp, ell, R_a_unit, ...
                                       I_vec, K_I, c);
    b_unit = [bx; by; bz];               % 3N×1
    
    % VarPro analytical C
    C_opt = (b_unit' * b_fem) / (b_unit' * b_unit);
    residual = C_opt * b_unit - b_fem;
    cost = sum(residual.^2);
end

% --- 主程式 ---
% Phase 1: 粗掃
ell_grid = linspace(400e-6, 2000e-6, 300);
costs = arrayfun(@(e) fit_ell_cost(e, p_FEM, b_FEM, w, K_I, c), ell_grid);
[~, idx_min] = min(costs);
ell_0 = ell_grid(idx_min);

% Phase 2: 精煉
ell_star = fminbnd(@(e) fit_ell_cost(e, p_FEM, b_FEM, w, K_I, c), ...
                   ell_0 - 200e-6, ell_0 + 200e-6, ...
                   optimset('TolX', 1e-12));

% Step 4: 取 C_opt + R_a
[~, C_opt] = fit_ell_cost(ell_star, p_FEM, b_FEM, w, K_I, c);
R_a = c.N_c / (c.mu_0 * abs(C_opt));
```

### 2.5 數值結果（V4 halfcut, P1）

```
ell* = 835.4 µm           Long Fei 論文: 900 µm
C_opt = 7.59 × 10⁻²       對應 R_a = 9.21 × 10⁸ A/Wb
Mean vector error = 4.94%
Max vector error  = 7.94%

Cost landscape:
    ell = 705 µm: cost ratio 1.05× (相對 minimum)
    ell = 835 µm: cost ratio 1.00× (minimum)
    ell = 1026 µm: cost ratio 1.08×
    → 100 µm cube 內 cost landscape 平坦, ell 約束弱
```

### 2.6 角色

[A] 是 **baseline**：
- ✅ 跟龍飛論文最接近 → 可直接做 reproducibility 對照
- ✅ 提供 ell 數值給 [B-6x] 當鎖定參數
- ❌ 4.94% error 偏大；幾何約束（共用 ell + 固定方向）犧牲精度
- ❌ 100 µm cube 內衰減模式不明顯，ell 約束不強

### 2.7 物理意涵

[A] 的 ell = 835 µm ≠ 物理 tip 距離 (500 µm)。意思是：

> 「等效點電荷的最佳位置在 tip **後方** 335 µm（深入 pole 鋼體）」

物理解釋：磁通不集中在 tip apex，而是沿著 cone 表面 + 鋼體有 finite 分布。等效 point 落在「分布有效質心」上，自然在 tip 後方。**這就是 Long Fei 論文 b=0 假設下的「實際磁荷位置」**。

---

## 3. Method [J] — 6-coil joint 自由 3D 擬合（24 參數）

**腳本**：`magnetic_sim/ANSYS/backup/hexapole-long2016/analysis/test_joint_6coil_fit.m`
**輸出**：`data/joint_6coil_19param_fit.mat`
**主結果**：Lower |c| avg 815.9 µm, Upper |c| avg 766.9 µm, R_a avg 1.01×10⁹, mean err 1.11%

### 3.1 假設（完全放開龍飛）

- **6 顆 charge 的 18 個座標完全自由**（每顆獨立 3D）
- 每組 coil 有自己的 **C_k**（共 6 個，per-coil 解析解）
- → 完全 free fit，看 charge 自然落在哪
- 用 **6 個 coil** 全部數據聯合 fit

### 3.2 為什麼需要 6 個 coil 一起 fit？

單 coil 數據時：

```
激勵 P1 → w = [5/6, −1/6, −1/6, −1/6, −1/6, −1/6]
              主極 ← 5 個被動極 →
              
P1 weight = 0.833 → 對 P1 位置敏感
P2~P6 weight = 0.167 → 對 P2-P6 位置幾乎不敏感
```

→ 單 coil 時 5 個被動極**位置不可辨識**（cost landscape 對它們極平坦，spread > 1000 µm）。

6 coil joint 時，每顆 pole 在某組數據中是主導 (5/6)，輪流被「點亮」→ 全部 6 個位置都可辨識。

### 3.3 數學參數化

```
模型 (對 coil k):
    B_k(p) = C_k · Σᵢ wᵢ(k) · (p − cᵢ) / |p − cᵢ|³

    wᵢ(k) = (K_I · I_vec_k)ᵢ      ← 跟 coil 編號 k 有關

待 fit:
    18 個位置座標 (c₁, c₂, ..., c₆) — 數值搜尋
    6 個 C_k (per-coil) — VarPro 解析
    
資料:
    6 coils × 647 nodes × 3 components = 11,646 個 B 觀測值
```

### 3.4 演算法詳細步驟

```
Step 0: 載入 6 組 coil 資料
    For k = 1..6:
        d_k = import_ansys_data(['coil' k], 'all', ['coil' k])
        應用同樣鐵芯過濾 + 100 µm cube
        p_FEM_k = positions, b_FEM_k = B 場堆疊
    Concatenate: 全部 6 組分開儲存

Step 1: 設定每個 coil 的 K_I weights
    For k = 1..6:
        paper_idx = apdl_to_paper_idx(k)
        I_vec_k = zeros(6,1); I_vec_k(paper_idx) = +1
        w_k = K_I · I_vec_k
        coil_sign_k = +1 (lower) or −1 (upper)

Step 2: 初始猜測（從 [A] 結果出發）
    ell_0 = 835 µm (from Method A)
    c_i_init = ell_0 · d̂_i,  i = 1..6
    
    x_0 = [c₁; c₂; ...; c₆]    ← 18×1 vector

Step 3: 定義 joint cost function
    function J = joint_cost(x):
        c_i = reshape(x, 6, 3)   ← 把 18×1 還原成 6 個 3D 位置
        J_total = 0
        For k = 1..6:
            b_unit_k = build_unit_field(c_i, w_k, p_FEM_k)
            C_opt_k = (b_unit_k' · b_FEM_k) / (b_unit_k' · b_unit_k)
            residual_k = C_opt_k · b_unit_k − b_FEM_k
            J_total += sum(residual_k.²)
        return J_total

Step 4: fminsearch 在 18 維搜尋
    x_opt = fminsearch(@joint_cost, x_0, optimset('TolX', 1e-10, ...))

Step 5: 唯一性驗證（5 組不同初始條件）
    For trial = 1..5:
        x_0_trial = x_0 + random_perturbation(50 µm scale)
        x_opt_trial = fminsearch(@joint_cost, x_0_trial, ...)
    
    spread_per_pole = std(x_opt_trials, axis=0)
    確認 spread < 1 µm 才算唯一

Step 6: 取每個 coil 的 C_opt_k + 對應 R_a_k
    For k = 1..6:
        b_unit_k = build_unit_field(c_i_opt, w_k, p_FEM_k)
        C_opt_k = (b_unit_k' · b_FEM_k) / (b_unit_k' · b_unit_k)
        R_a_k = N_c / (μ₀ · |C_opt_k|)
    
    R_a_avg = mean(R_a_k)  ← 通常 spread ~2%
```

### 3.5 MATLAB code 骨架

```matlab
% --- joint_cost.m ---
function J = joint_cost(x, p_FEM_all, b_FEM_all, w_all, c)
    % x: 18×1 = [c1_xyz; c2_xyz; ...; c6_xyz]
    charges = reshape(x, [3, 6])';        % 6×3
    
    J = 0;
    for k = 1:6
        % Build unit field for coil k
        b_unit_k = build_unit_field(charges, w_all(:,k), ...
                                     p_FEM_all{k});
        % VarPro analytical C_k
        b_fem_k = b_FEM_all{k};
        C_k = (b_unit_k' * b_fem_k) / (b_unit_k' * b_unit_k);
        residual = C_k * b_unit_k - b_fem_k;
        J = J + sum(residual.^2);
    end
end

% --- 主程式 ---
ell_0 = 835e-6;
c_init = ell_0 * d_hat;                  % 6×3
x_0 = c_init(:);                         % 18×1

opts = optimset('TolX', 1e-10, 'TolFun', 1e-22, ...
                'MaxIter', 50000, 'MaxFunEvals', 100000);

x_opt = fminsearch(@(x) joint_cost(x, p_FEM_all, b_FEM_all, w_all, c), ...
                   x_0, opts);

% 唯一性驗證
results = zeros(18, 5);
for trial = 1:5
    x_perturbed = x_0 + randn(18,1) * 50e-6;
    results(:, trial) = fminsearch(@(x) joint_cost(...), x_perturbed, opts);
end
spread_per_pole = std(reshape(results, [3, 6, 5]), 0, 3);
% → 結果: spread < 0.5 µm 對所有 pole ✓
```

### 3.6 數值結果（V4 halfcut, 6 coil joint）

Per-pole charge 距離（|c_i|）：

```
P1 (Lower halfcut): 814.8 µm     P2 (Upper full):  765.8 µm
P3 (Lower halfcut): 817.3 µm     P4 (Upper full):  768.2 µm
P6 (Lower halfcut): 815.2 µm     P5 (Upper full):  766.8 µm
                    ──────                          ──────
Lower 平均:         815.9 µm     Upper 平均:        766.9 µm
                    Δ = 49 µm (Lower charge 比 Upper 遠 6%)
```

Per-coil C/R_a：

```
Coil 1: R_a = 1.019 × 10⁹     Coil 4: R_a = 1.001 × 10⁹
Coil 2: R_a = 1.014 × 10⁹     Coil 5: R_a = 1.008 × 10⁹
Coil 3: R_a = 1.010 × 10⁹     Coil 6: R_a = 1.005 × 10⁹
                              ──────
                              avg = 1.01 × 10⁹ A/Wb, spread 2%

Mean vector error = 1.11%
Max vector error  = 2.83%
```

Charge 偏離 cone 軸（方向偏差）：

```
Pole   Layer    Dev [°]   r_perp [µm]   r_cone [µm]   Inside?
P1     Lower    1.55      163.7         93.2          NO (出 cone)
P3     Lower    1.28      168.4         93.2          NO
P6     Lower    1.69      162.2         93.5          NO
P2     Upper    5.49      67.2          92.1          YES
P4     Upper    5.59      68.7          92.5          YES
P5     Upper    5.59      68.6          92.2          YES
```

→ **Lower charge 跑出 cone 外** 70 µm（向 −z 偏 ~163 µm）；Upper charge 還在 cone 內但有 5.5° 偏軸。

### 3.7 角色

[J] 是 **物理觀察工具**：
- ✅ 完全 free fit → 真實 charge 位置會自然偏離 b=0 多少都看得到
- ✅ 6 coil joint → 識別性極佳（per-pole spread 0.3 µm，5 組初始條件確認唯一解）
- ✅ 精度提升 4.5× (4.94% → 1.11%)
- ❌ 24 自由度太多，每組 coil 自己一個 C_k 不太符合「single global R_a」物理

### 3.8 量化「b 偏離 0 多少」

跟 [A] 的球面假設 (ell = 835) 比，[J] 揭示：

| 觀察 | 物理意涵 |
|---|---|
| Lower vs Upper |c| 差 49 µm | 半切下極 vs 完整上極幾何不對稱 |
| Lower charge 偏 cone 軸 1.5° | 半切後磁荷中心略偏（往 −z 偏 163 µm） |
| Upper charge 偏 cone 軸 5.5° | 完整錐 + yoke 不對稱 |
| Lower charge **跑出 cone 外** | 磨平半錐使等效中心向 −z 偏移 |
| Upper charge 在 cone 內 | 完整錐保留對稱性 |

→ **b=0 假設在 halfcut 設計下不嚴謹**。對 Long Fei 的 b=0 推導不是致命錯誤（error 從 1% 變 5%），但量化結果證明 b≠0 才是物理事實。

---

## 4. Method [B-6x] — ell+δ 全激勵擬合（19 參數）★ 定案

**腳本**：`magnetic_sim/ANSYS/backup/hexapole-long2016/analysis/fit_all6_with_bias.m`
**輸出**：`data/all6_bias_fit.mat`
**主結果**：ell = 835 µm (fixed), R_a = 1.03×10⁹, mean err **0.07%**（達 point-charge model 物理極限）

### 4.1 假設（混搭 [A] + [J]）

- ell 鎖定 = [A] 結果 (835 µm) → 用「球面錨點」當隱式正則化
- 每顆 charge 可偏離球面 → 18 個 δ_i 自由（位置在 ell·d̂_i 上**再加** δ_i）
- **共用同一個 C**（更符合 Long Fei 物理：global R_a 只應該一個值）
- 用 **all6 superposition 數據**（6 顆 coil 同時通 ±1A，FEM 線性疊加）

### 4.2 為什麼用 all6 superposition？

APDL 模擬「全部 6 顆同時 +1A」時，因 SOURC36 繞線方向：

```
Lower (P1/P3/P6) +1A → tip = SINK    → I_diss = +1
Upper (P2/P4/P5) +1A → tip = SOURCE  → I_diss = −1

I_diss = [+1, −1, +1, −1, −1, +1]  (對偶 pair ±1, paper 順序)
sum(I_diss) = 0  →  w = K_I · I_diss = I_diss

→ 所有 6 顆 pole 都有 |w| = 1（等權重）
```

✅ vs single-coil 的 5/6 vs 1/6 不均：[B-6x] 每顆 pole **同等強度約束**，identifiability 大幅提升
✅ 線性疊加：B(all6) = B(coil1) + ... + B(coil6) 直接從 6 顆獨立 sim 加總（已用 `verify_superposition.m` 驗證）

### 4.3 數學參數化

```
位置:    c_i = ell_fixed · d̂_i + δ_i
        (ell_fixed = 835 µm 鎖死, δ_i ∈ ℝ³ 自由)
        i = 1..6, 共 18 個 δ 座標

權重:   w = I_diss = [+1, −1, +1, −1, −1, +1]ᵀ  (paper 順序)

模型:   B_all6(p) = C · Σᵢ w_i · (p − c_i) / |p − c_i|³

待 fit:
    18 個 δ_i 座標 — 數值搜尋
    1 個 C — VarPro 解析

資料: all6 ±1A 對應的 647 nodes × 3 components = 1941 個 B 觀測值
```

### 4.4 演算法詳細步驟

```
Step 0: 取得 all6 superposition 資料
    Option A (直接 sim): 跑 APDL 全 6 顆同時 ±1A
    Option B (疊加): 把 6 個獨立 coil sim 結果線性加總
        b_FEM_all6 = Σ_k b_FEM_coil_k       ← 已驗證 < 0.1% error
    
    取 100 µm cube → 647 nodes
    b_FEM = [bx; by; bz]    ← 1941×1

Step 1: 取 ell_fixed (from Method A)
    Load 'data/charge_model_fit.mat' → ell_fixed = 835 µm
    
    建構球面錨點:
    For i = 1..6:
        anchor_i = ell_fixed · d̂_i

Step 2: 設定 I_diss 與 w
    I_diss = [+1, −1, +1, −1, −1, +1]ᵀ
    w = K_I · I_diss
    驗證 sum(I_diss) = 0 → w = I_diss (磁通守恆)

Step 3: 初始猜測
    δ_i = 0,  i = 1..6
    x_0 = zeros(18, 1)

Step 4: 定義 cost function (B-6x 專屬)
    function J = b6x_cost(x):
        δ = reshape(x, 6, 3)        ← 6 個 3D δ
        For i = 1..6:
            c_i = anchor_i + δ_i
        
        b_unit = build_unit_field(c_i, w, p_FEM)
        C_opt = (b_unit' · b_FEM) / (b_unit' · b_unit)
        residual = C_opt · b_unit − b_FEM
        J = sum(residual.²)
        
        return J

Step 5: fminsearch 在 18 維搜尋
    opts = optimset('TolX', 1e-12, 'TolFun', 1e-22, ...
                    'MaxIter', 100000, 'MaxFunEvals', 200000)
    x_opt = fminsearch(@b6x_cost, x_0, opts)
    
    δ_opt = reshape(x_opt, 6, 3)
    c_opt = anchor + δ_opt          ← 6×3 最終位置

Step 6: 取最終 C_opt + R_a
    b_unit_opt = build_unit_field(c_opt, w, p_FEM)
    C_opt = (b_unit_opt' · b_FEM) / (b_unit_opt' · b_unit_opt)
    R_a = N_c / (μ₀ · |C_opt|)
    
Step 7: 算誤差
    B_pred = C_opt · b_unit_opt
    residual = B_pred − b_FEM
    err_per_node = ‖residual_j‖ / ‖B_FEM_j‖
    mean_err = mean(err_per_node)        ← 應該 ~0.07%
    
Step 8: 多次擾動測試（confirm 是 global min）
    For trial = 1..5:
        x_perturbed = x_0 + randn(18, 1) · 50e-6
        x_opt_trial = fminsearch(...)
    
    所有 trial 都收斂到同一個 δ_opt (spread < 0.5 µm) ✓
```

### 4.5 MATLAB code 骨架

```matlab
% --- b6x_cost.m ---
function J = b6x_cost(x, anchor, w, p_FEM, b_FEM)
    % x: 18×1 = [δ1; δ2; ...; δ6]
    delta = reshape(x, [3, 6])';         % 6×3
    charges = anchor + delta;             % 6×3 位置
    
    % Build unit field (C = 1)
    b_unit = build_unit_field(charges, w, p_FEM);  % 3N×1
    
    % VarPro analytical C
    C_opt = (b_unit' * b_FEM) / (b_unit' * b_unit);
    residual = C_opt * b_unit - b_FEM;
    J = sum(residual.^2);
end

% --- 主程式 ---
% Load Method [A] 結果
A_result = load('data/charge_model_fit.mat');
ell_fixed = A_result.ell;                % 835 µm

% Build anchor
[d_hat, ~] = build_pole_directions(c);
anchor = ell_fixed * d_hat;              % 6×3

% I_diss for all6 ±1A
I_diss = [1; -1; 1; -1; -1; 1];          % paper order
w = K_I * I_diss;                         % = I_diss because sum=0

% Load all6 data (或從 6 顆 coil 疊加)
p_FEM = load_p_FEM_all6();
b_FEM = load_b_FEM_all6();

% fminsearch
x_0 = zeros(18, 1);
opts = optimset('TolX', 1e-12, 'TolFun', 1e-22, ...
                'MaxIter', 100000, 'MaxFunEvals', 200000);

x_opt = fminsearch(@(x) b6x_cost(x, anchor, w, p_FEM, b_FEM), x_0, opts);

delta_opt = reshape(x_opt, [3, 6])';     % 6×3
charges_opt = anchor + delta_opt;

% 取 C_opt + R_a
b_unit_opt = build_unit_field(charges_opt, w, p_FEM);
C_opt = (b_unit_opt' * b_FEM) / (b_unit_opt' * b_unit_opt);
R_a = c.N_c / (c.mu_0 * abs(C_opt));     % 1.03 × 10⁹
```

### 4.6 數值結果（V4 halfcut, all6 ±1A）

```
ell (fixed) = 835 µm
R_a = 1.03 × 10⁹ A/Wb
Mean vector error = 0.07%    ← point-charge model 的物理極限
Max  vector error = 0.19%
```

Per-pole charge 距離（|c_i| = |anchor + δ_i|）：

```
P1 (Lower): ~781 µm        P2 (Upper): ~734 µm
P3 (Lower): ~783 µm        P4 (Upper): ~734 µm
P6 (Lower): ~780 µm        P5 (Upper): ~734 µm
            ─────                      ─────
Lower 平均: ~781 µm        Upper 平均: ~734 µm
            Δ = 47 µm  ← 跟 [J] 的 49 µm Δ 一致
```

跟 [J] 比，[B-6x] 的 |c| 都被 ell-anchor 拉回約 35 µm（[J]: 816/767 vs [B-6x]: 781/734），但 Lower/Upper 不對稱 pattern 完全一致。

### 4.7 角色

[B-6x] 是 **定案**：
- ✅ **精度 0.07%** ≈ point-charge model 的物理極限
- ✅ 共用 1 個 C → 符合 Long Fei 物理（single global R_a）
- ✅ 19 自由度（比 [J] 的 24 少）+ 隱式正則化（ell-anchor）→ 更穩健
- ✅ all6 等權約束 → identifiability 最好
- ⚠️ 需先跑 [A] 才能取 ell

### 4.8 為什麼 [B-6x] 比 [J] 還準?

| 因素 | [J] | [B-6x] | 影響 |
|---|---|---|---|
| 數據型態 | 6 個 single-coil (5/6 vs 1/6 不均) | all6 等權 (|w_i|=1) | 等權給 identifiability 大幅提升 |
| C 個數 | 6 個 (per-coil) | 1 個 (共用) | 共用更符合 single R_a 物理 + 約束更強 |
| 位置參數化 | 全自由 (18 dim) | ell + δ (隱式正則化) | δ 不能跑太遠 → 抑制 overfit |
| 結果 error | 1.11% | 0.07% | 16× 改善 |

→ [B-6x] 是「正確物理約束 + 等權數據 + 隱式正則化」三件事一起做好的結果。

---

## 5. 三方法對比

### 5.1 結果總表

```
Method   Params   ell [µm]   R_a [A/Wb]    Mean err   Data        Identifiable?
[A]         2     835        9.21 × 10⁸    4.94%      1 coil      ✓
[J]        24     767-818    1.01 × 10⁹    1.11%      6 coils     ✓ (need ≥6 coils)
[B-6x]    19     734-783    1.03 × 10⁹    0.07%      all6        ✓ ★ 定案

Long Fei   ~2    ~900       ~6.3 × 10⁸    ~1%        ?           ✓
```

### 5.2 誤差來源分解

從 [A] 的 4.94% 開始，逐步放鬆假設後誤差降到哪：

```
Point-charge model 固有極限              ~0.07%  ([B-6x] 達到)
  + 共用 ell + 固定方向 (球面約束)      ~1.04%  ([A] 有, [J]/[B-6x] 無)
  + 6 個 C_k + 非等權 (single coil)     ~3.83%  ([A] 有, [B-6x] 用 all6 解決)
─────────────────────────────────────────────
  [A] total                              4.94%
  [J] total                              1.11%  (放開球面 + 用 6 coil)
  [B-6x] total                           0.07%  (all6 + 共用 C + 隱式正則化)
```

→ **球面約束**佔 ~21% 誤差、**非等權單 coil**佔 ~77%。後者是主要 killer。

### 5.3 何時用哪個

| 用途 | 推薦 method |
|---|---|
| Reproduce Long Fei (b=0 假設) | **[A]** |
| 量化「真實 b 偏離 0 多少」 | **[J]** |
| 力模型 / 控制器設計（要 high accuracy + global R_a） | **[B-6x]** ★ |
| 快速 sanity check 新 sim batch | [A]（最便宜） |
| 論文 Ch2.2.3 主結果 | **[B-6x]**（定案） + 對照 [A] 跟龍飛數值 |

### 5.4 R_a 跟論文不一致 (~6.3e8 vs ~1e9)

所有方法的 R_a 都比論文高 ~1.5×。

主因：APDL 用 **μ_r = 280** 線性近似（低場初始磁導率），高於實際操作點（B ~ 1T）對應的 μ_r ≈ 1400 + BH 飽和效應。低 μ_r → 鋼導磁能力差 → 磁通洩漏多 → 高階多極成分大 → 6-monopole 近似精度下降 + R_a 偏大。

✅ V4 halfcut 結果**內部一致**，可作橫向比較
⚠️ 跟 Long Fei 論文絕對數值有 ~25-50% 差距，需在論文 Ch2.2.3 註明此 caveat

---

## 6. 對龍飛 b=0 假設的回饋

### 6.1 我們的三個 fit 量化了什麼？

| 龍飛聲稱 | 我們發現 | 論文位置 |
|---|---|---|
| 「Charges 都在 ρ=900 µm 球面」 | 物理上等效中心比物理 tip (500 µm) 後移 280-340 µm，球面假設**近似成立** | [A]/[J]/[B-6x] 都同意 |
| 「b=0」 | Lower (halfcut) charge 跑出 cone 外 163 µm，Upper 偏軸 5.5° → **b≠0** | [J] 揭示 |
| 「Lower/Upper 對稱（共用 ρ）」 | Lower 比 Upper 遠 ~50 µm（一致橫跨 [J]/[B-6x]） | [J]/[B-6x] 一致 |
| 「Fit error < 1%」 | 嚴格 b=0 (我們 [A]) 給 ~5%；放開 b 才達 ~1%，[B-6x] 達 0.07% | [B-6x] 最強 |

### 6.2 結論

> **龍飛論文 Section 2.3 「Assume b=0 for the nominal force model」是 modeling convenience，不是物理事實**。
>
> b≠0 在 halfcut 下極特別明顯（charge 跑出 cone）。Force model closed-form inverse 推導若用嚴格 b=0 會引入系統誤差 ~5%；要做 high-accuracy control 必須用 [B-6x] 等級的 fit 把 b 還原。

### 6.3 對 kuo 論文 Ch2.2.3 / Ch3 的建議

1. **Ch2.2.3 改寫**：
   - 重做龍飛 Fig 2.6 對照（用 [A] 結果，verify b=0 假設下 error ~5%）
   - 新增 Fig 2.6'：用 [J] 揭示 Lower charge 跑出 cone 的 quantitative 圖
   - 新增 Fig 2.6"：[B-6x] 的 ε ≈ 0.07% 達到 point-charge floor

2. **Ch3 開頭 sensitivity section**：
   - 把 b=0 vs b-free RMS 差距量化（4.94% vs 0.07%）
   - 點明「b=0 適用於 closed-form inverse model 推導；但 forward prediction high accuracy 需用 [B-6x]」

---

## 7. 腳本/資料/圖檔清單

### 7.1 腳本（在 `magnetic_sim/ANSYS/backup/hexapole-long2016/analysis/`）

| 檔案 | 用途 | 對應方法 |
|---|---|---|
| `mt_constants.m` | 幾何常數、極頭座標 | 所有 |
| `import_ansys_data.m` | 載入 FEM `.dat` | 所有 |
| `filter_iron_nodes.m` | 排除鐵芯節點 | 所有 |
| `point_charge_model.m` | 6-pole B 場計算（含 K_I） | 所有 |
| `fit_charge_model.m` | 2-param 球面 fit | **[A]** |
| `test_joint_6coil_fit.m` | 24-param 6-coil joint free 3D | **[J]** |
| `fit_all6_with_bias.m` | 19-param ell+δ all6 | **[B-6x]** ★ |
| `verify_superposition.m` | all6 = Σ coil_k 驗證 | [B-6x] 前置 |

### 7.2 數據

| 檔案 | 內容 |
|---|---|
| `data/charge_model_fit.mat` | [A] 結果 (ell, R_a, error) |
| `data/joint_6coil_19param_fit.mat` | [J] 結果 (6 個 c_i, R_a per-coil) |
| `data/all6_bias_fit.mat` | [B-6x] 結果 (6 個 δ_i, single R_a) ★ |

### 7.3 圖

| 檔案 | 對應論文 Fig |
|---|---|
| `generate_figures_2_3.m` | Fig 2.3 (B vector near tip 收斂) |
| `generate_figures_2_4.m` | Fig 2.4 (|B| contour) |
| `generate_figures_2_6.m` | Fig 2.6 用 [A] |
| `generate_fig26_coil1.m` | Fig 2.6 用 [J] |
| `plot_fig26_B6x.m` | Fig 2.6 用 [B-6x] ★ |

---

## 8. 名詞速查

| 符號 | 意義 | 典型值 |
|---|---|---|
| B(p) | 磁通密度 [T] | ~mT 量級在 WP |
| **k_m** | 磁 Coulomb 常數 = μ₀/(4π) | **10⁻⁷ N/A²** |
| μ₀ | 真空磁導率 | 4π×10⁻⁷ T·m/A |
| q_i, c_i | 第 i 顆 charge 強度 / 位置 | 10⁻⁹ A·m / mm |
| ξ | fit 用合併振幅 = -k_m·N_c/(μ₀·R_a) | VarPro 解析解 |
| Q | 磁荷向量 [q_1..q_6] | |
| K_I | 名義磁通分佈矩陣 (I₆ − 1₆/6) | 對角 5/6, 非對角 −1/6 |
| ell (ρ) | 等效磁荷距離（球面半徑） | 835 µm ([A]) vs 900 µm (Long Fei) |
| δ_i | charge i 相對球面的偏移 (b_i) | [B-6x] 自由 fit, [A] = 0 |
| R_a | 集總空氣磁阻 [A/Wb] | ~1×10⁹ ([B-6x]) vs 6.3×10⁸ (Long Fei) |
| α | 極角 | 54.74° (= arctan √2) |
| R_norm | WP 中心到極尖物理距離 | 500 µm |
| C | 振幅因子 = N_c/(μ₀·R_a) | VarPro 解析解 |
| d̂_i | pole i 從 WP 中心的單位方向 | 由 (θ_i, α, z_sign_i) 決定 |
| w_i | charge i 的相對權重 = (K_I·I_vec)_i | 5/6 主極, −1/6 被動極 |
| coil_sign | Lower=+1 / Upper=−1 (SOURC36 繞線修正) | |
| anchor_i | [B-6x] 用的球面錨點 = ell_fixed · d̂_i | |

---

## 9. 延伸閱讀

- **原始技術文件**：`magnetic_sim/ANSYS/backup/hexapole-long2016/docs/charge-model-fitting.md`（完整推導，1300+ 行）
- **方法總結**：`magnetic_sim/ANSYS/backup/hexapole-long2016/docs/fitting-methods.md`（精簡版）
- **Long Fei 原文**：dissertation Section 2.2.3 (printed page 17-20), Eq 2.1-2.4
- **Memory**：[[J-fit-validity-by-pole-shape]] — cylinder vs cone-fillet validity 邊界差 4×
- **相關**：[[long-fei-vs-paper-lab406]] — paper LAB406 與 dissertation 的 ρ 不一致根因

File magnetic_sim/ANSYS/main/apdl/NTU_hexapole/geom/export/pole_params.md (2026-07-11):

# NTU_hexapole — `pole.STEP` 尺寸提取表（params）

**來源 CAD**：`CAD_model/NTU_hexapole/STEP/pole.STEP`（STEP AP214, SI_UNIT `.MILLI. .METRE.` → **mm**；1 solid；全解析面：15 條 edge、無 b-spline）。
**座標系**：**沿用 STEP 檔原點（不平移）**（使用者 2026-07-11 拍板）。
**零件**：一片**扁平「平面磁極」**——2D 輪廓（對稱於 y=0）沿 +z **拉伸 0.25 mm**。

## 厚度 / z
| 項 | 值 | 來源 |
|---|---|---|
| 板厚（z 範圍） | 0.000 → 0.250 mm（**0.25 mm**） | EDGE_CURVE 垂直邊（z0↔z0.25），全頂點成對 |

## 2D 輪廓邊界環（z=0 面，逆時針 A→…→A；單位 mm）
對稱於 y=0；上半 (y≥0) 由下半鏡射。9 段封閉環：

| # | 段 | 起點 (x,y) | 終點 (x,y) | 型別 | 圓心 (x,y) | 半徑 | 來源 EDGE_CURVE |
|---|---|---|---|---|---|---|---|
| 1 | 尖端圓角上 | A (0.357, 0.005) | B (0.353, 0.000) | ARC | (0.358, 0.000) | 0.005 | #156 |
| 2 | 尖端圓角下 | B (0.353, 0.000) | C (0.357, −0.005) | ARC | (0.358, 0.000) | 0.005 | #36 |
| 3 | 下側直邊1 | C (0.357, −0.005) | D (4.509, −0.523) | LINE | — | — | #309 |
| 4 | 下側凹弧 | D (4.509, −0.523) | E (6.175, −0.877) | ARC | (3.271, −10.446) | 10.000 | #199 |
| 5 | 下側直邊2 | E (6.175, −0.877) | F (19.048, −4.784) | LINE | — | — | #87 |
| 6 | 遠端底弧（**凸/major 213°**） | F (19.048, −4.784) | G (19.048, 4.784) | ARC | (20.500, 0.000) | 5.000 | #305 |
| 7 | 上側直邊2 | G (19.048, 4.784) | H (6.175, 0.877) | LINE | — | — | #115 |
| 8 | 上側凹弧 | H (6.175, 0.877) | I (4.509, 0.523) | ARC | (3.271, 10.446) | 10.000 | #117 |
| 9 | 上側直邊1 | I (4.509, 0.523) | A (0.357, 0.005) | LINE | — | — | #25 |

## 關鍵幾何量（幾何註記，非原點）
| 量 | 值 | 說明 |
|---|---|---|
| pole_tip（尖端銳點） | ≈ (0.358, 0) | 5µm 圓角鈍尖；**距 STEP 原點 0.358 mm**（不移原點） |
| 全長（tip→遠端凸弧頂點 x） | ~25.15 mm（x 0.353→**25.5**） | 遠端 r5 為**凸 major arc**、頂點 (25.5,0)（=圓心 20.5+半徑 5）；此頂點非 CARTESIAN_POINT 頂點故不在 bbox 頂點清單 |
| 底半寬 | ±4.784 mm @ x≈19.048 | 最寬邊界頂點（弧再往外凸到 x=25.5） |
| 板厚 | 0.25 mm | z 拉伸 |
| 對稱 | 對稱於 y=0 | 上下半鏡射 |

## 備註 / 坑
- z ~1000 的 CARTESIAN_POINT 為向量 artifact，非幾何；已排除。
- (3.271,±10.446)、(20.5,0) 是**圓弧圓心構造點**（非邊界頂點）。
- 遠端 r5 弧：STEP EDGE_CURVE #305 sense .T.、CCW about +z、v1(19.048,−4.784)→v2(19.048,+4.784) 經 0°→ **凸 major arc（213°）頂點 (25.5,0)**。ANSYS LARC 只做 ≤180°，故**拆成兩段 <180° LARC**（經頂點 K10=(25.5,0)）。（初版誤判為 minor 凹弧、已更正。）
- 5µm 尖端圓角：metre BTOL 1e-7 m 可解析；如後續 mesh 有困難再議簡化。

---

# 短導柱（短導柱.STEP）尺寸提取 + pole 組合

**來源**：`CAD_model/NTU_hexapole/STEP/短導柱.STEP`（mm、1 solid、全解析、無 b-spline）。
**做成實心整根**（使用者拍板：省略尖端凹陷/銑平）。standalone 沿 Z 軸：r2.5 z−11→0、r2.49 z0→6（尖端）。

## ⚠ 組裝位置＝OCC 烘焙 transform（不可用 raw 同框）
pole組合.STEP 是**組裝檔**，每零件存**自己 local frame + transform**。用 OpenCascade(OCP) 烘焙後之世界座標 bbox：
| 零件 | standalone 中心 | 組裝後中心 | transform |
|---|---|---|---|
| 磁極 | (12.93,0,0.12) | (13.70,−2.10,1000.0) | (+0.78,−2.10,+999.88) #589 |
| 短導柱 | (0,0,−2.5) | (21.28,−2.10,1008.6) | (+21.28,−2.10,+1011.13) #104（無旋轉）|
| 襯套 | (0,0,1.6) | (21.28,−2.10,1008.5) | #449（+旋轉~7.2°）|

**模型框＝磁極 local frame**（＝pole.iges 的框）→ 短導柱相對偏移 = **(+20.5, 0, +11.25)**。

## 短導柱在磁極框的幾何（實心）
| 段 | 半徑 | z 範圍（磁極框） | 說明 |
|---|---|---|---|
| 軸線 | — | x=20.5, y=0、直立 +Z | 底坐磁極板頂面(z=0.25) 於 x≈20.5（近凸端 x25.5）|
| 下段圓柱 | 2.500 | 0.25 → 11.25 | 實心（standalone z−11→0 + 11.25）|
| 上段圓柱 | 2.490 | 11.25 → 17.25 | 實心尖端（standalone z0→6 + 11.25；**無銑平/凹陷**）|

## 組合（磁極 + 短導柱）
- 建模腳本 `MT_Geom_PoleAssembly.txt`：磁極段（profile+VEXT）+ 短導柱（`WPOFFS` 到軸線 + 2×CYLIND 實心）= **3 volumes、暫不 boolean**（保留兩件、供位置目視檢查）。post 底坐落板頂面（相接）。

## 下游
- 磁極單件：`MT_Geom_Pole.txt` → `model_check/NTU_hexapole/pole.iges`（mm）。
- **組合件**：`MT_Geom_PoleAssembly.txt` → `model_check/NTU_hexapole/pole_assembly.iges`（mm、flag 2）。

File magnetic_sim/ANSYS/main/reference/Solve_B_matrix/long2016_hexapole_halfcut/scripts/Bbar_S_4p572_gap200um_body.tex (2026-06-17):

\[
\bar{B}_S^{\,\mathrm{gap200um}} =
\begin{bmatrix}
 +0.017845 &  -0.001756 &  +0.001271 &  -0.008676 &  -0.008780 &  +0.001274 \\
 -0.002278 &  +0.025548 &  -0.002356 &  -0.009374 &  -0.009423 &  -0.002363 \\
 +0.001337 &  -0.008437 &  +0.017242 &  -0.001689 &  -0.008482 &  +0.001348 \\
 -0.002255 &  -0.009244 &  -0.002402 &  +0.026042 &  -0.009402 &  -0.002420 \\
 -0.002189 &  -0.009151 &  -0.002123 &  -0.009267 &  +0.025343 &  -0.002080 \\
 +0.001155 &  -0.008924 &  +0.001156 &  -0.008942 &  -0.001919 &  +0.018463 \\
\end{bmatrix}\ \mathrm{T}
\]

\noindent Geometry: Long Fei halfcut hexapole + \textbf{single-side 200~$\mu$m yoke-pole air gap}, $\mu_r = 280$.\\
Sensor: 4.572 mm along + 0.41 mm normal (0.3 mm $\varnothing$, 721-pt).\\
Test current $I_{in} = 0.60$~A.\\
Columns sign-flipped vs raw FEM: zeros(1,0).

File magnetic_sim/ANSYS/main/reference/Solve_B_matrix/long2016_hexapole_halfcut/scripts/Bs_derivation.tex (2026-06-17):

\documentclass[12pt,a4paper]{article}

\usepackage{amsmath}
\usepackage{amssymb}
\usepackage{xeCJK}
\usepackage{geometry}
\usepackage{graphicx}
\geometry{margin=2.5cm}

\setCJKmainfont{Noto Sans CJK TC}

\setlength{\parindent}{0pt}
\setlength{\parskip}{6pt}

\begin{document}

\section{Derivation: $V_{out}/V_{in}$}

\begin{enumerate}
    \item 令輸入為 $I_{in}$,輸出為 $V_{out} = V_{ij}$。

    其中
    \begin{equation}
        V_{ij} = S \cdot B_{ij}
    \end{equation}

    則
    \begin{equation}
        \frac{V_{ij}}{I_{in}} = \frac{S}{I_{in}}
        \begin{bmatrix}
            B_{11} & \cdots & \cdots & \cdots & \cdots & B_{16} \\
            B_{21} & \cdots & \cdots & \cdots & \cdots & B_{26} \\
            B_{31} & \cdots & \cdots & \cdots & \cdots & \vdots \\
            B_{41} & \cdots & \cdots & \cdots & \cdots & \vdots \\
            B_{51} & \cdots & \cdots & \cdots & \cdots & \vdots \\
            B_{61} & \cdots & \cdots & \cdots & \cdots & B_{66}
        \end{bmatrix}
        = \frac{S}{I_{in}} \overline{B}_S
    \end{equation}

    其中 $B_{ij}$ 為激發第 $j$ 個磁極、從第 $i$ 個磁極量測到之磁通密度,$S$ 為霍爾感測器敏感度。

    \item 考慮放大器 $\Rightarrow I_{in} = V_{in} \cdot k_A$

    則
    \begin{equation}
        \frac{V_{out}}{V_{in}} = \underbrace{\frac{k_A \cdot S}{I_{in}}}_{\alpha}\,\overline{B}_S
    \end{equation}
\end{enumerate}

\section{Sensor placement}

每顆磁極都依照 Long Fei 標準:沿磁極表面 4.572 mm + 垂直磁極表面 0.41 mm,Hall sensor 直徑 0.3 mm,disc 平均(721 點 annular sampling)。

\textbf{Lower poles (P1/P3/P6)} — milled flat (halfcut 切割面),$\hat{n}_+$ 純垂直 milled flat 向外。

\textbf{Upper poles (P2/P4/P5)} — 沿 cone top slant 4.572 mm + 垂直 slant 0.41 mm,$\hat{n}_+ = (-\sin\beta, \cos\beta, 0)$ in pole-local,$\beta = \arctan(3/15) \approx 11.31^\circ$。

\section{FEM 結果 (Long2016 verbatim baseline)}

\textbf{模擬條件}:Long2016 verbatim halfcut hexapole,$\mu_r = 280$,$I_{in} = 1.0$ A,每顆 coil 70 匝 CCW (looking from $+z$),mesh node $\approx 494{,}873$ 一致。Sign convention: 對每根磁極 $j$,raw FEM 矩陣的第 $j$ 行乘以 $\mathrm{sign}(\bar{B}_S(j,j))$ 使對角為正(+I 對應 yoke $\to$ tip $\to$ WP)。

\subsection{$\overline{B}_S$ matrix (Tesla)}

\input{Bbar_S_4p572_body.tex}

\subsection{$V_{out}/V_{in}$ matrix (dimensionless)}

$V_{out}/V_{in} = k_A \cdot S_{\mathrm{Hall}} / I_{in} \cdot \overline{B}_S$,with $k_A = 0.3614$\,A/V (power amplifier gain),$S_{\mathrm{Hall}} = 130$\,V/T (EQ-730L)。

\input{Vout_Vin_4p572_body.tex}

\subsection{Lower vs Upper diagonal}

\begin{tabular}{lll}
\hline
組別 & 磁極 & $\bar{B}_S$ 對角 (mT) \\
\hline
Lower (halfcut D-shape) & P1, P3, P6 & 10.6, 11.5, 10.2 (avg 10.74) \\
Upper (full cone)       & P2, P4, P5 & 9.5, 9.4, 9.5 (avg 9.49) \\
\hline
\multicolumn{2}{l}{比例 Lower / Upper} & 1.13 \\
\hline
\end{tabular}

Lower halfcut 把 cone 削掉一半,殘餘截面 flux 集中,fringe 在 milled flat 上方反而更強;upper full cone flux 在整個截面分散,fringe 較弱。

\end{document}

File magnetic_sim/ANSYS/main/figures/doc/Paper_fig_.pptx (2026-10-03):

## A Lumped-Parameter Modeling, Calibration, and Capacity-Measure Framework for Flux Generation in Symmetric Multipole Electromagnetic Actuators

## Current-based lumped-parameter modeling and calibration

E. Validation

- Interpolation Point Algorithm for workspace pseudocode

Algorithm 1 Generate Interpolation Points
Input: Na, R
Output: pa (Ntot × 3) // interpolation point
1: d ← R / Na // point to point distance
2: Ntot ← 1 + 6·Na // total number of points
3: pa ← zeros(Ntot, 3)
4: E ← eye(3) // unit vectors of three axes
5: cnt ← 1; pa(cnt, :) ← [0, 0, 0] // center point
6: for j = 1 to 3 do
7: for s ∈ {+1, −1} do // ± direction
8: for i= 1 to Na do
9: cnt ← cnt + 1
10: pa(cnt, :) ← s · i · d · E(j, :) // i-th point on axis j
11: end for
12: end for
13: end for
14: return pa

Algorithm 2 Barycentric Interpolation
Input: pa (Ntot × 3), p (Np × 3) // FEM points , b(p) (Np × 3 × Ns) // FEM Flux density
Output: b(pa) (Ntot × 3 × Ns)
1: T ← DelaunayTriangulation(p) // rebuild connectivity
2: for q = 1 to Ntot do
3: (tetID, λ) ← PointLocation(T, pa(q, :)) // enclosing tetrahedron
// λ=( λ_1 , λ_2 , λ_3 , λ_4 ): weight
4: (v1, v2, v3, v4) ← ConnectivityList(T, tetID) // 4 interpolation nodes
// (v1, v2, v3, v4) : FEM node number
5: for s = 1 to Ns do
6: b(pa)(q, :, s) ← Σ λi · b(p) (vi, :, s), i = 1,…,4 // weighting
7: end for
8: end for
9: return b(pa)

## Current-based lumped-parameter modeling and calibration

E. Validation

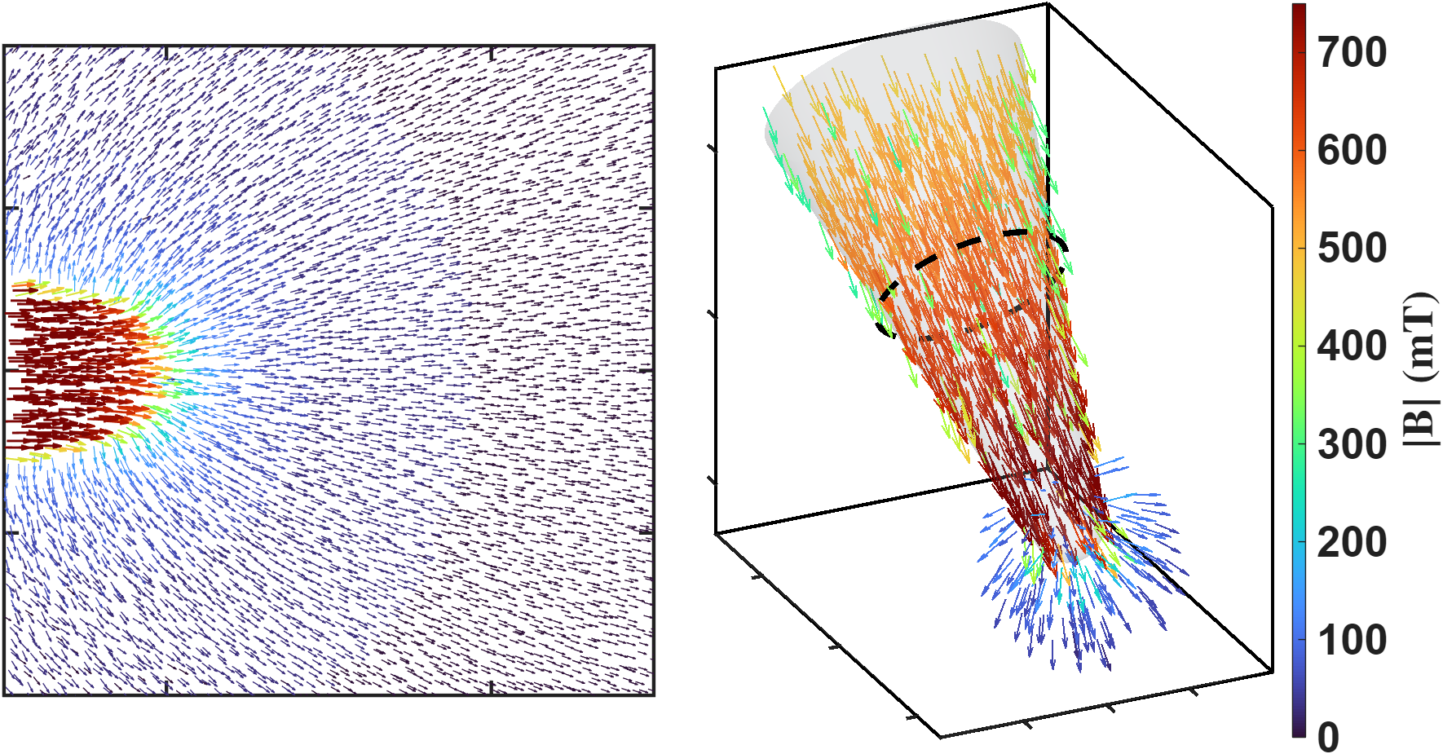
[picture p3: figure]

Φ

q

q

- This figure illustrates the magnetic flux path when pole P2 is excited. The left figure presents a top view, with the theoretical magnetic charge locations labeled to clarify the magnetic charge concept used in this study. The right figure shows a three-dimensional view of the same model, in which the theoretical magnetic charge locations and the magnetic flux distribution can be clearly observed.
- The threshold used in the 3D plot on the right is 0.1 mT, meaning that only values greater than 0.1 mT are displayed in the figure.

## Current-based lumped-parameter modeling and calibration

E. Validation

Workspace radius (μm)

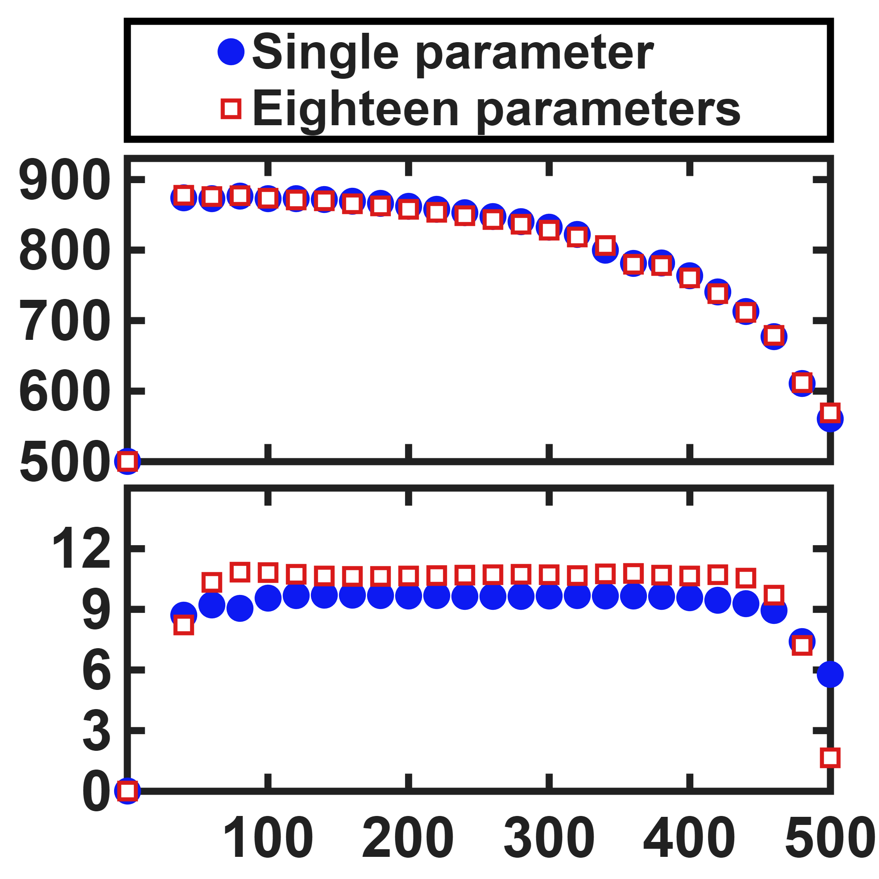
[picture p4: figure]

ℓ (μm)

Bg_I ((mT)/A)

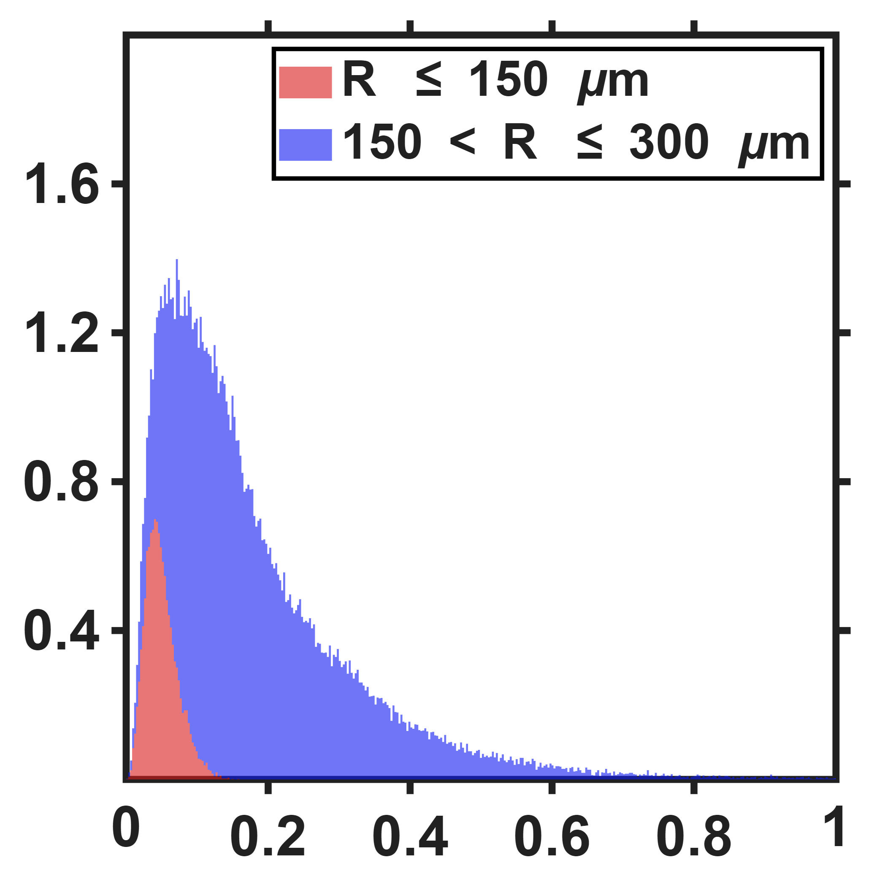
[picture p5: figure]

Percentage count (%)

Modeling error (mT)

## Quantitative Assessment of Multi-Pole Actuators

Setup: The assessment that follows compares two six-pole actuator designs, Design 1 on a circular yoke and Design 2 on a planar square frame. Both are described by the same lumped-parameter model and use the pole numbering P1-P6 shown here.
Sharing the model form and the pole numbering, the two differ only in geometry, so their calibrated parameters can be compared directly in the following slides.

- DesignA

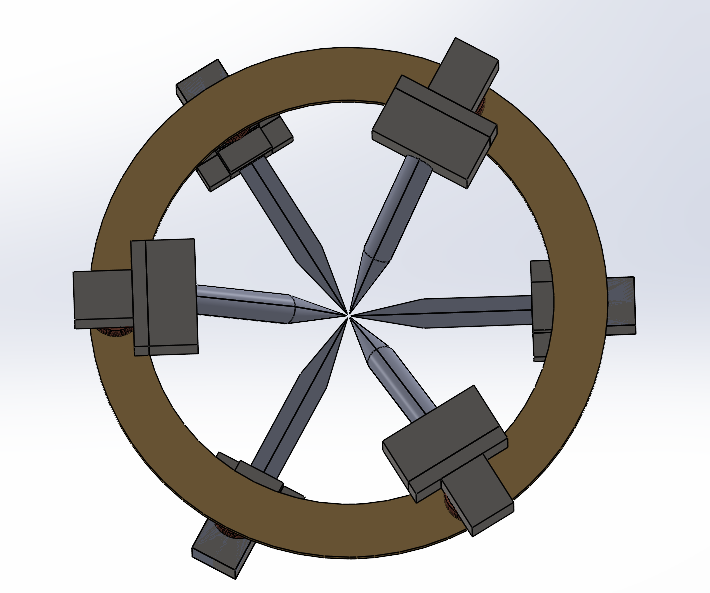
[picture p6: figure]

P2

P3

P5

P6

P4

P1

- DesignB

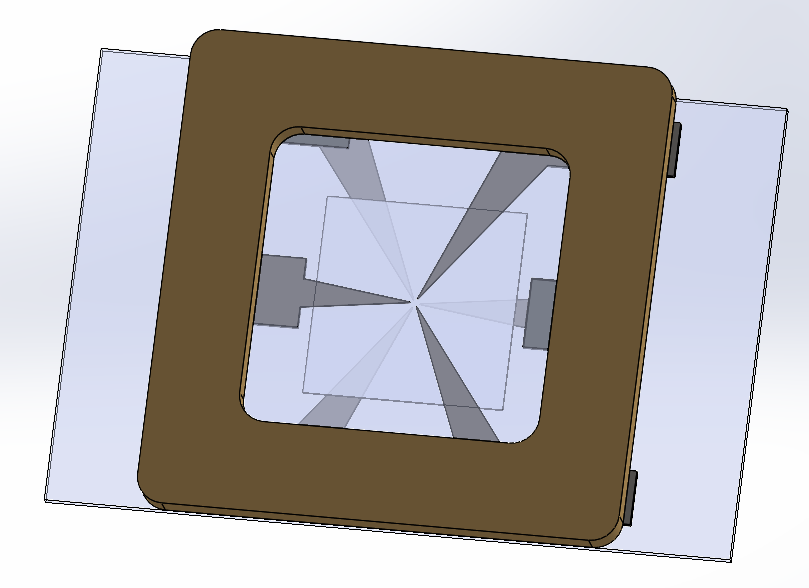
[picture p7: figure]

P2

P3

P5

P6

P4

P1

## Quantitative Assessment of Multi-Pole Actuators

- DesignA

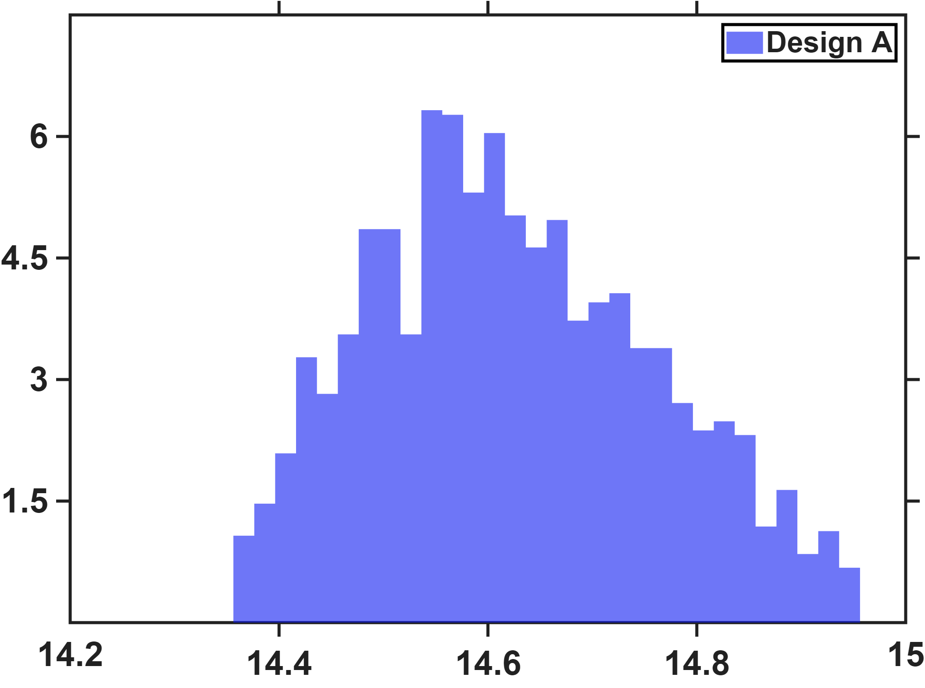
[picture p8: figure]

d ((mT)/A)

Percentage count (%)

- Histogram resolution 0.02 (mT)/A

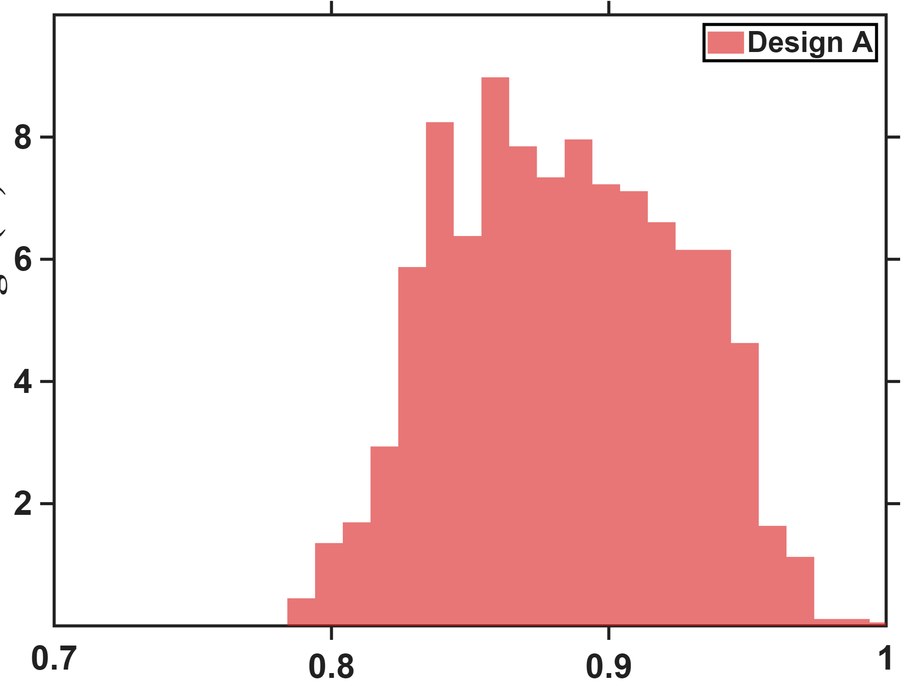
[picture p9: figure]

Percentage count (%)

Isotropy

- Histogram resolution 0.01

Mean ((mT)/(A)) | 0.8836

Mean ((mT)/(A)) | 14.6246

## Quantitative Assessment of Multi-Pole Actuators

- DesignB

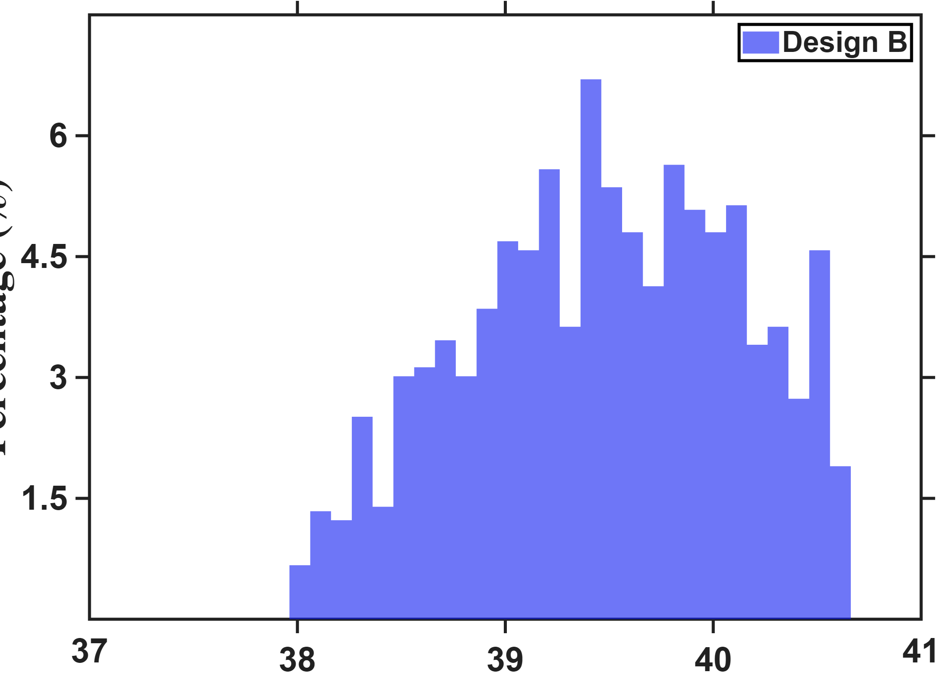
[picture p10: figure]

Capacity measure ((mT)/A)

Percentage count (%)

- Histogram resolution 0.02 (mT)/A

Mean ((mT)/(A)) | 39.4683

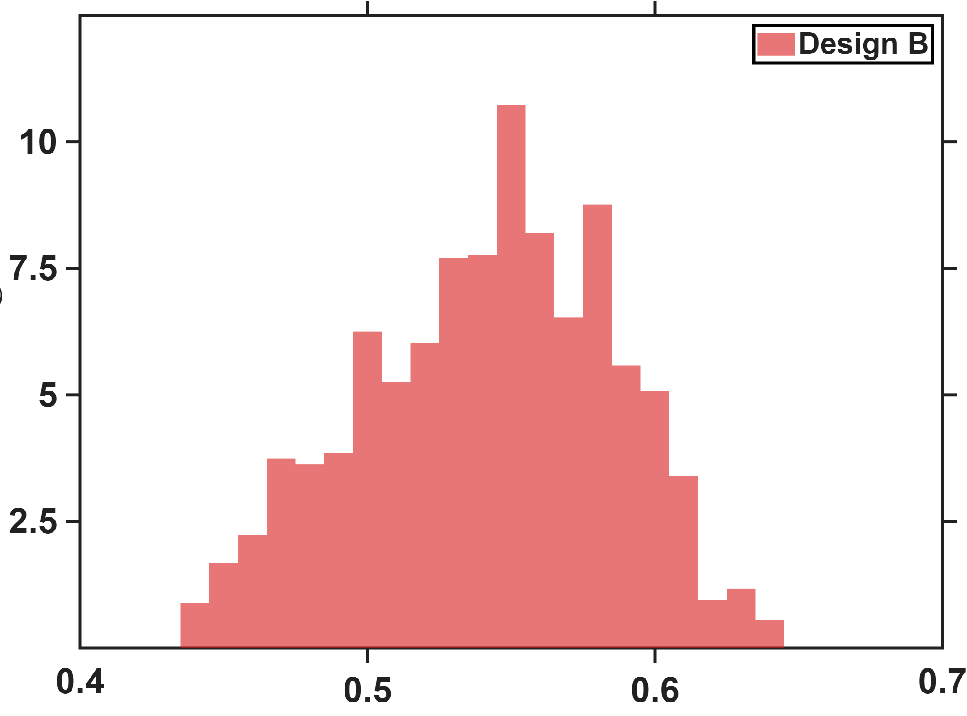
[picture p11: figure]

Percentage count (%)

Isotropy

- Histogram resolution 0.01

Mean ((mT)/(A)) | 0.5415

## Quantitative Assessment of Multi-Pole Actuators

- DesignB(Have gap)

Capacity measure ((mT)/A)

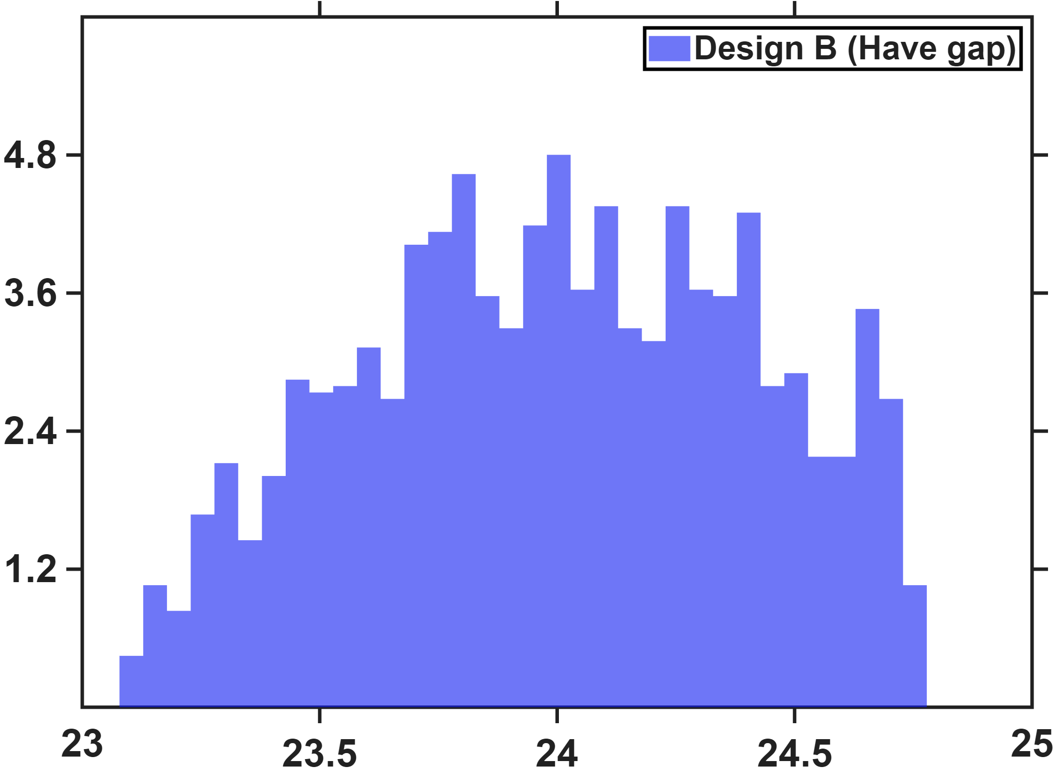
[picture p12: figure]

Percentage count (%)

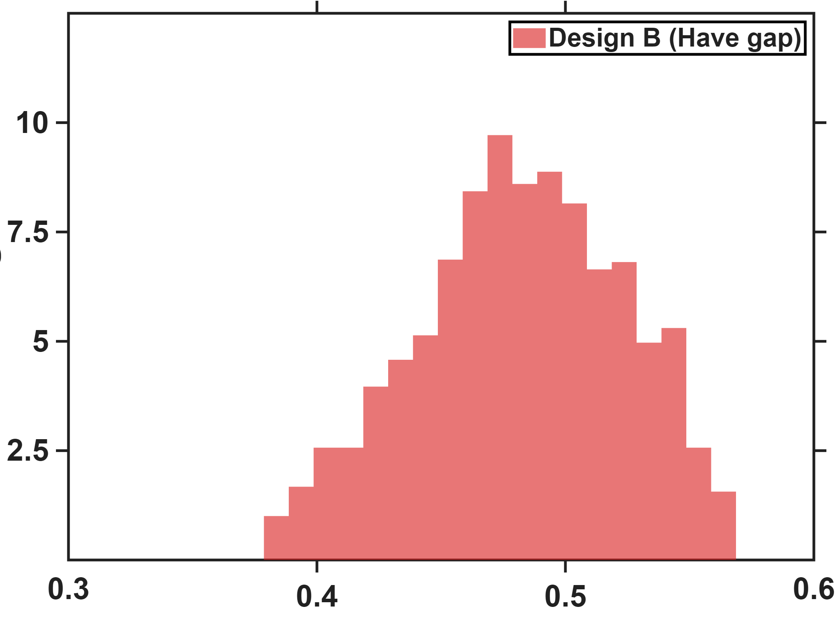
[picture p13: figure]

Percentage count (%)

Isotropy

- Histogram resolution 0.01

Mean ((mT)/(A)) | 0.4820

- Histogram resolution 0.02 (mT)/A

Mean ((mT)/(A)) | 23.9991

## Reference

- Workspace radius=ℓ

- Flux distribution matrix=K_I

- Current to field gain=Bg_I

- Predict error=√(J/(N_p)) , where J=∑_j ∑_i ε_(ij) ^T ε_(ij)

- Voltage to field gain=Bg_V

- Capacity measure=C ((mT)/A)

- Isotropy=κ

- Frobenius error=(‖K_I −K_(I,all_grid) ‖_F)/(‖K_(I,all_grid) ‖_F)

- Average field=(∑_j ∑_i ‖b_(ij) ‖)/(6×N_p)

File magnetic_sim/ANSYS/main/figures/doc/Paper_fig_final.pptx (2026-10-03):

## A Lumped-Parameter Modeling, Calibration, and Capacity-Measure Framework for Flux Generation in Symmetric Multipole Electromagnetic Actuators

## Current-based lumped-parameter modeling and calibration

E. Validation

- Interpolation Point Algorithm for workspace pseudocode

Algorithm 1 Generate Interpolation Points
Input: Na, R
Output: pa (Ntot × 3)
1: d ← R / Na // division spacing
2: Ntot ← 1 + 6·Na // total number of points
3: pa ← zeros(Ntot, 3)
4: E ← eye(3) // unit vectors of three axes
5: cnt ← 1; pa(cnt, :) ← [0, 0, 0] // center point
6: for j = 1 to 3 do
7: for s ∈ {+1, −1} do // ± direction
8: for i = 1 to Na do
9: cnt ← cnt + 1
10: pa(cnt, :) ← s · i · d · E(j, :) // i-th point on axis j
11: end for
12: end for
13: end for
14: return pa

Algorithm 2 Barycentric Interpolation
Input: pa (Ntot × 3), p (Np × 3), b(p) (Np × 3 × Ns)
Output: b(pa) (Ntot × 3 × Ns)
1: T ← DelaunayTriangulation(p) // rebuild connectivity
2: for q = 1 to Ntot do
3: (tetID, λ) ← PointLocation(T, pa(q, :)) // enclosing tetrahedron
4: (v1, v2, v3, v4) ← ConnectivityList(T, tetID) // 4 interpolation nodes
5: for s = 1 to Ns do
6: b(pa)(q, :, s) ← Σ λi · b(p) (vi, :, s), i = 1,…,4 // weighting
7: end for
8: end for
9: return b(pa)

## Current-based lumped-parameter modeling and calibration

E. Validation

Φ

q

q

- This figure illustrates the magnetic flux path when pole P2 is excited. The left figure presents a top view, with the theoretical magnetic charge locations labeled to clarify the magnetic charge concept used in this study. The right figure shows a three-dimensional view of the same model, in which the theoretical magnetic charge locations and the magnetic flux distribution can be clearly observed.
- The threshold used in the 3D plot on the right is 0.1 mT, meaning that only values greater than 0.1 mT are displayed in the figure.

## Current-based lumped-parameter modeling and calibration

E. Validation

- The convergence criterion is defined as follows: check whether ℓ and Bg_I remain within ±0.2% of their steady-state values for ten consecutive points. If this condition is satisfied, the first point is taken as the convergence point. (R≤150μm)
- Long

Number of point (N_p )

ℓ (μm)

Number of point (N_p )

ℓ (μm)

Bg_I ((mT)/A)

Number of point (N_p )

Number of point (N_p )

Bg_I ((mT)/A)

| Number of points at convergence | Calibration value at the convergence point | Calibration value using all nodes | Steady-state value
Single parameter | ℓ(7)∩Bg_I (25)→25 points | 870.59μm | 874.25 μm | 871.00 μm
| | 9.67(mT)/A | 9.67 (mT)/A | 9.69 (mT)/A
Eighteen parameters | ℓ(7)∩Bg_I (13)→13 points | 867.186μm | 873.96 μm | 868.57 μm
| | 10.6244(mT)/A | 10.75 (mT)/A | 10.64 (mT)/A

## Current-based lumped-parameter modeling and calibration

E. Validation

- The convergence criterion is defined as follows: check whether ℓ and Bg_I remain within ±0.2% of their steady-state values for ten consecutive points. If this condition is satisfied, the first point is taken as the convergence point. (R≤150μm)
- Zhi peng

Number of point (N_p )

ℓ (μm)

Number of point (N_p )

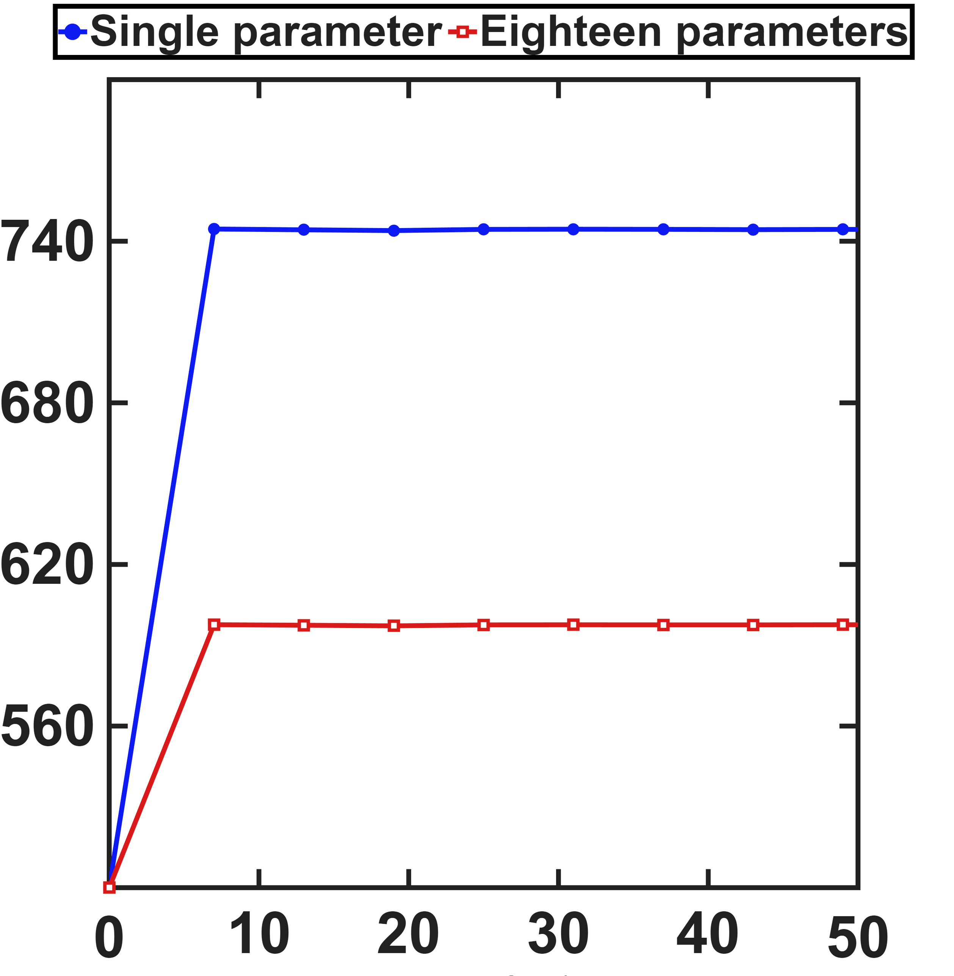
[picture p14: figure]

ℓ (μm)

Bg_I ((mT)/A)

Number of point (N_p )

Number of point (N_p )

Bg_I ((mT)/A)

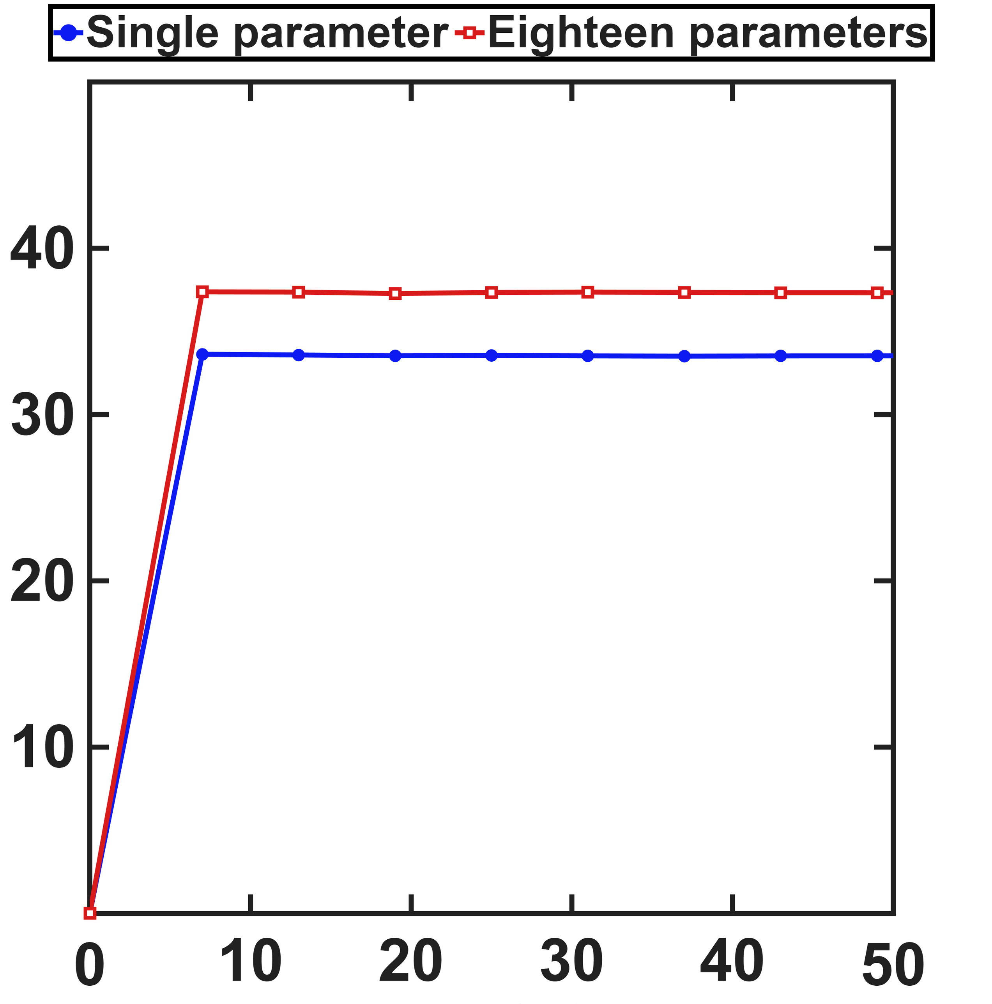
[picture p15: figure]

| Number of points at convergence | Calibration value at the convergence point | Calibration value using all nodes | Steady-state value
Single parameter | ℓ(7)∩Bg_I (13)→13 points | 744.24μm | 7 45.01μm | 7 44.66μm
| | 33.58(mT)/A | 3 3.09(mT)/A | 3 3.53(mT)/A
Eighteen parameters | ℓ(7)∩Bg_I (7)→7 points | 597.62μm | 6 04.14μm | 5 97.87μm
| | 37.38(mT)/A | 3 7.56(mT)/A | 3 7.33(mT)/A

## Current-based lumped-parameter modeling and calibration

E. Validation

- Calibration results

Calibrate model→b_(ij) =S_i Bg_I K_I I_j

- R≤150um
- Calibration results obtained using the interpolation points determined above.
- Long calibrate results

- Single parameter(25 points)

K_I = [0.8333, −0.0946, −0.2002, −0.1664, −0.1727, −0.1965−0.2151, 0.9630, −0.2182, −0.1508, −0.1567, −0.2140−0.1905, −0.1671, 0.8264, −0.0967, −0.1727, −0.1965−0.2074, −0.1505, −0.2238, 0.9575, −0.1555, −0.2133−0.2080, −0.1506, −0.2176, −0.1510, 0.9557, −0.2213−0.1903, −0.1666, −0.1996, −0.1667, −0.1018, 0.8275]

ℓ = 870.6 μm Bg_I = 9.67 mT/A

NMAE=(∑_j ∑_i ‖b_(ij) −S_i Bg_I K_I I_j ‖)/(∑_j ∑_i ‖b_(ij) ‖)∙100%=2.81%

- Eighteen parameters(13 points)

K_I = [0.8333, −0.1382, −0.1334, −0.1889, −0.1927, −0.1320−0.1395, 0.8381, −0.2070, −0.1220, −0.1254, −0.2063−0.1320, −0.1984, 0.8461, −0.1361, −0.1960, −0.1345−0.2039, −0.1264, −0.1400, 0.8415, −0.1260, −0.2072−0.2091, −0.1281, −0.2122, −0.1257, 0.8574, −0.1443−0.1320, −0.1972, −0.1352, −0.1918, −0.1356, 0.8404]

e= [0.0136, 0.0213, −0.1165, 0.0005, −0.0002, −0.1175−0.1142, 0.0019, 0.0199, 0.0187, 0.0002, −0.11620.1150, −0.0025, 0.1157, −0.0012, −0.0112, −0.0178]

ℓ = 867.2 μm Bg_I = 10.62 mT/A

NMAE=(∑_j ∑_i ‖b_(ij) −S_i Bg_I K_I I_j ‖)/(∑_j ∑_i ‖b_(ij) ‖)∙100%=0.35%

## Current-based lumped-parameter modeling and calibration

E. Validation

- Calibration results

Calibrate model→b_(ij) =S_i Bg_I K_I I_j

- R≤150um
- Calibration results obtained using the interpolation points determined above.
- Zhi peng calibrate results

- Single parameter(7 points)

K_I = [0.8333, −0.0639, −0.2179, −0.1082, −0.1076, −0.2163−0.0630, 0.8255, −0.1093, −0.2206, −0.2202, −0.1077−0.2480, −0.0996, 0.7428, −0.0560, −0.0718, −0.2343−0.0996, −0.2522, −0.0574, 0.7368, −0.2383, −0.0727−0.0995, −0.2522, −0.0735, −0.2386, 0.7357, −0.0554−0.2482, −0.0997, −0.2355, −0.0722, −0.0563, 0.7449]

ℓ = 744.5 μm Bg_I = 33.63 mT/A

NMAE=(∑_j ∑_i ‖b_(ij) −S_i Bg_I K_I I_j ‖)/(∑_j ∑_i ‖b_(ij) ‖)∙100%=10.53%

- Eighteen parameters(7 points)

K_I = [0.8333, −0.1078, −0.1162, −0.1870, −0.1870, −0.1162−0.1107, 0.8260, −0.1914, −0.1201, −0.1198, −0.1906−0.1345, −0.1938, 0.7481, −0.0935, −0.1572, −0.1313−0.1972, −0.1383, −0.0970, 0.7389, −0.1348, −0.1609−0.1977, −0.1385, −0.1612, −0.1353, 0.7403, −0.0971−0.1345, −0.1936, −0.1308, −0.1569, −0.0931, 0.7466]

e= [−0.0008, 0.0013, −0.2149, 0.2140, 0.2148, −0.2140−0.2137, 0.2139, 0.0011, 0.0002, 0.2156, −0.21380.2136, −0.2143, 0.2143, −0.2150, 0.0009, −0.0003]

ℓ = 597.6 μm Bg_I = 37.38 mT/A

NMAE=(∑_j ∑_i ‖b_(ij) −S_i Bg_I K_I I_j ‖)/(∑_j ∑_i ‖b_(ij) ‖)∙100%=0.75%

## Current-based lumped-parameter modeling and calibration

E. Validation

- Transforming e_a into the measurement coordinate system makes the primary direction of the magnetic charge displacement more apparent. It can be observed that the displacement of P1 occurs mainly in the x_m −z_m plane, which is physically reasonable. e_m =R^T e_a

- Calibration results

Calibrate model→b_(ij) =S_i Bg_I K_I I_j

- Long bias at measure coordinate system

e_m = [0.1047, 0.0156, −0.0560, −0.0077, −0.0048, −0.05580.0005, −0.0005, 0.0959, 0.0124, −0.0078, −0.09470.1245, −0.0148, 0.1226, −0.0118, −0.0065, 0.1247]

R= [0.8165, 0, −0.5774−0.4082, 0.7071, −0.57740.4082, 0.7071, 0.5774]

- Zhi peng bias at measure coordinate system

e_m = [0.1738, −0.1738, −0.0884, 0.0869, 0.0877, −0.0875−0.0001, −0.0003, 0.1523, −0.1519, 0.1530, −0.15140.2472, −0.2479, 0.2472, −0.2477, −0.2479, 0.2468]

## Current-based lumped-parameter modeling and calibration

E. Validation

- This figure shows the trends of the calibration results for ℓ and Bg_I for Long-Fei and Zhi-Peng, using the minimum number of points required for each working range.
- If no convergence point can be found within a given range for either the single-parameter model or the eighteen-parameter model, all nodes within that range are used for calibration instead. This is used only to illustrate the trend, and the values within that range are not used as a basis for calibration.

- Long

Workspace radius (μm)

ℓ (μm)

Bg_I ((mT)/A)

Workspace radius (μm)

ℓ (μm)

Bg_I ((mT)/A)

## Current-based lumped-parameter modeling and calibration

E. Validation

- This figure shows the trends of the calibration results for ℓ and Bg_I for Long-Fei and Zhi-Peng, using the minimum number of points required for each working range.
- If no convergence point can be found within a given range for either the single-parameter model or the eighteen-parameter model, all nodes within that range are used for calibration instead. This is used only to illustrate the trend, and the values within that range are not used as a basis for calibration.

- Zhi peng

Workspace radius (μm)

ℓ (μm)

Bg_I ((mT)/A)

Workspace radius (μm)

ℓ (μm)

Bg_I ((mT)/A)

## Current-based lumped-parameter modeling and calibration

E. Validation

- Both panels fit the point-charge model within R ≤ 150 µm. Sampling is the actuator-axis shell ladder — six pole axes Nr shells plus the centre , so Number of points = 6Nr+1, spanning 7 to 49. Frobenius error (%) is the relative error of K_I against the full-grid fit, shown for the single- and eighteen-parameter models.
- At their convergence points the reduced designs already reproduce the all-node K_I closely: Long gives 2.66 % with the single parameter (25 points) and 1.71 % with eighteen (13 points); Zhi-Peng converges at 7 points for both, at 2.10 % and 0.39 %. The eighteen-parameter fit is consistently closer to the all-node solution (≈1.8× for Long, ≈5× for Zhi-Peng), with the planar design benefiting far more. Extending to 49 points improves every curve by under one percentage point, so the K_I obtained at the convergence point already represents what the design can achieve and can replace the all-node calibration.

- Long

Number of point (N_p )

Frobenius error (%)

Number of point (N_p )

Frobenius error (%)

- Zhi peng

Number of point (N_p )

Frobenius error (%)

Number of point (N_p )

Frobenius error (%)

## Current-based lumped-parameter modeling and calibration

E. Validation

- Setup: The calibration side is identical to the previous slide: the same R sweep, the same converged reduced design at each R. What changes is the evaluation: the predict is computed on every real FEM node inside R.
- Predict error rises monotonically with workspace radius for both designs and degrades sharply beyond the 150 µm calibration radius: Long grows from 0.20 mT at R = 160 µm to 0.92 mT at 400 µm and 4.12 mT at 500 µm, while Zhi-Peng grows from 2.11 mT to 10.39 mT and 18.91 mT. The eighteen-parameter fit is lower at every radius, but its advantage collapses with R — from 7.6× to 1.07× for Long and from 13.2× to 1.8× for Zhi-Peng — showing that charge offsets correct near-field structure only and cannot compensate the far-field model error. Long remains about an order of magnitude more accurate than Zhi-Peng, so the conical hexapole extrapolates markedly better; for both, the model is trustworthy only near the calibration radius.

- Long

Workspace radius (μm)

Modeling error (%)

- Zhi peng

Workspace radius (μm)

Modeling error (%)

## Current-based lumped-parameter modeling and calibration

E. Validation

- This figure shows the fitting results for the FEM nodes within R≤150μm after both models were calibrated over the same region using their respective convergence points.This figure overlays the distributions of the two models. The red distribution is noticeably more concentrated than the blue one, indicating that the eighteen-parameter model performs better than the one-parameter model in fitting the magnetic field.
- Workspace radius: R≤150μm

Calibrate model→b_(ij) =S_i Bg_I K_I I_j

- Long( N_p :1771)

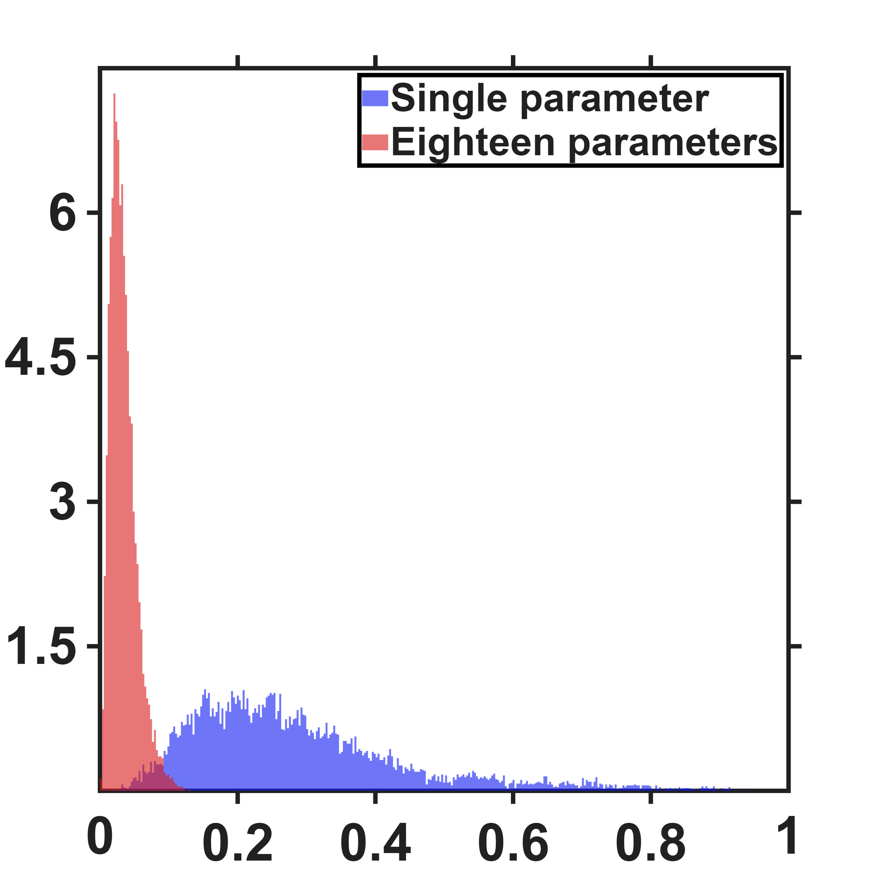
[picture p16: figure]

Modeling error (mT)

- Zhi peng ( N_p :1791)

Modeling error (mT)

Percentage count (%)

Percentage count (%)

- Resolution:17uT

| Single | Eighteen
Mean | 3.0658mT | 0.2190mT

- Resolution:2.8uT

| Single | Eighteen
Mean | 0.2878mT | 0.0340mT

## Current-based lumped-parameter modeling and calibration

E. Validation

- Setup: Calibration is performed using the eighteen-parameter calibration points, followed by fitting to the FEM nodes within the workspace.

- Long

Modeling error (mT)

Percentage count (%)

Modeling error (mT)

Percentage count (%)

| N_p | Peak value (R≤150μm) | Average field | Mean error
Left figure | 1771 | 7.237% | 10.2452mT | 0.0340mT
Right figure | 14082 | 0.3491% | 10.4684mT | 0.1271mT ( R≤150um) | 0.3019mT ( 150um≤R≤300um)

- Resolution:2.8uT

## Current-based lumped-parameter modeling and calibration

E. Validation

- Setup: Calibration is performed using the eighteen-parameter calibration points, followed by fitting to the FEM nodes within the workspace.

- Zhi peng

Modeling error (mT)

Percentage count (%)

Modeling error (mT)

Percentage count (%)

| N_p | Peak value (R≤150μm) | Average field | Mean error
Left figure | 1791 | 6.4954% | 29.1094mT | 0.2190mT
Right figure | 14066 | 0.4751% | 30.7330mT | 0.4294mT ( R≤150um) | 1.2666mT ( 150um≤R≤300um)

- Resolution:17uT

## Current-based lumped-parameter modeling and calibration

E. Validation

- Long

x_a

z−axis(mm)

q_(c2)

‖b‖(mT)

x_a

q_(c1)

x−axis(mm)

x−axis(mm)

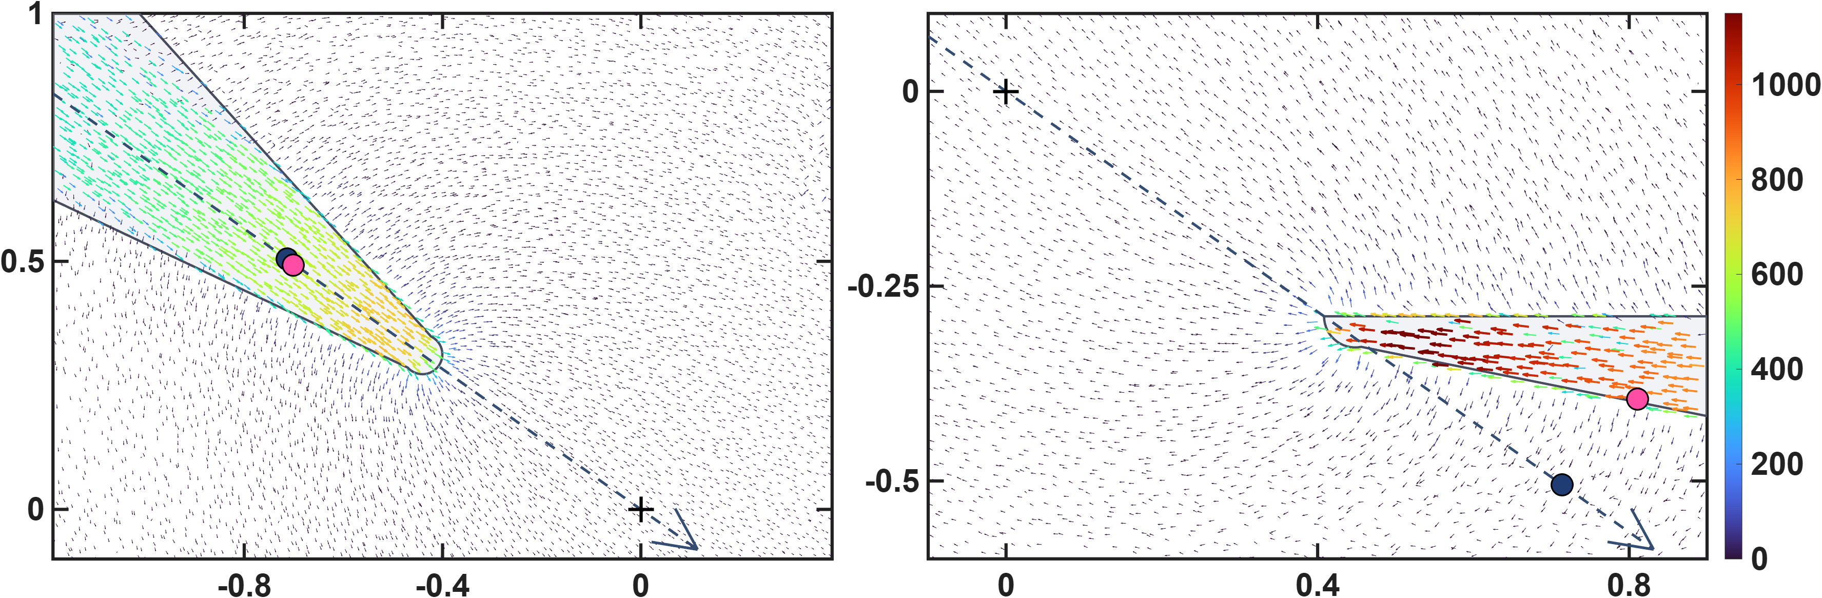
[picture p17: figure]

Calibrate model→b_(ij) =S_i Bg_I K_I I_j

- These two figures show the differences in the calibrated magnetic charge locations between the two models. The upper row presents the magnetic charge locations calibrated by the one-parameter model, shown using side views of poles P1 and P2. It can be clearly seen that, for the lower pole, some of the magnetic charge locations are located outside the pole. This is because the one-parameter model constrains the magnetic charges to lie along the actuator coordinate axes. The lower row presents the results of the eighteen-parameter model, in which the magnetic charge locations of the lower pole move inside the pole. This is more consistent with the expected physical situation. Moreover, the error histograms shown above also indicate that these magnetic charge locations are more consistent with the theoretical positions.

## Current-based lumped-parameter modeling and calibration

E. Validation

- Zhi peng

x_a

z−axis(mm)

q_(c2)

‖b‖(mT)

x_a

q_(c1)

x−axis(mm)

x−axis(mm)

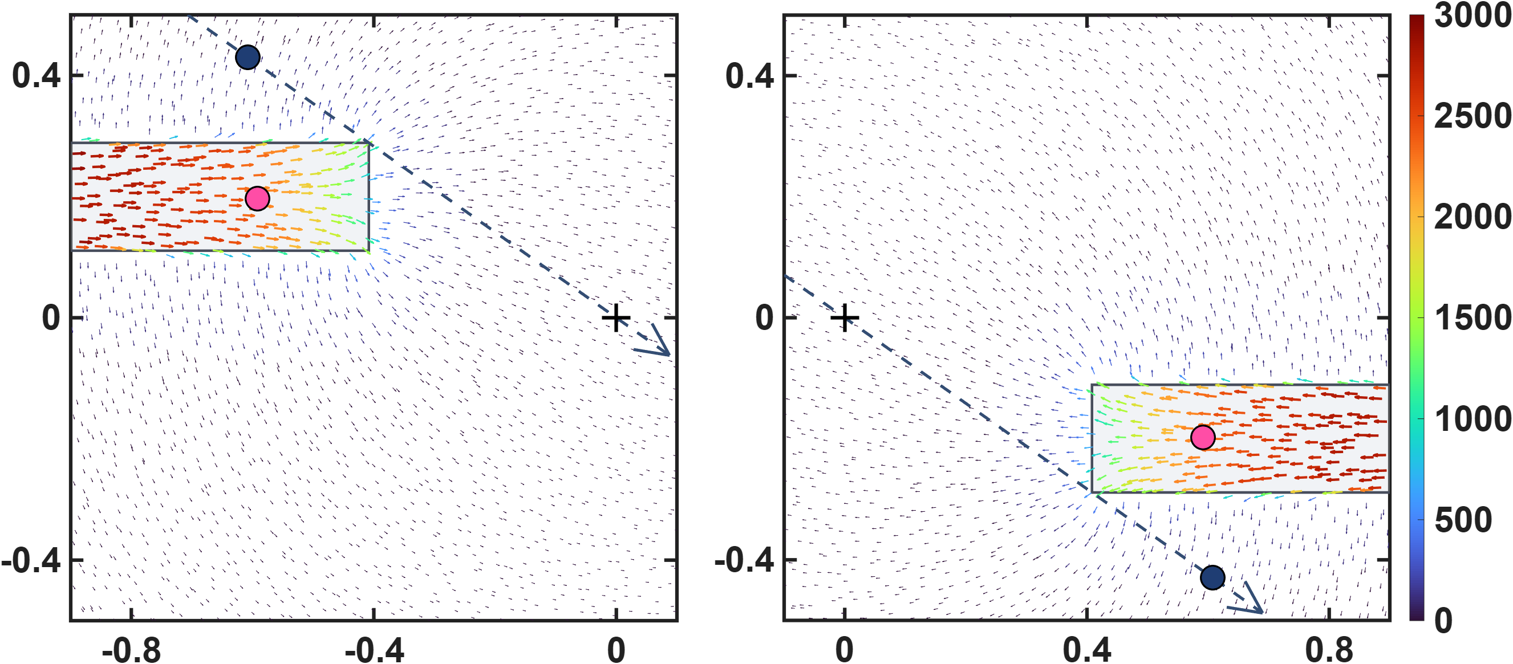
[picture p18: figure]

Calibrate model→b_(ij) =S_i Bg_I K_I I_j

- These two figures show the differences in the calibrated magnetic charge locations between the two models. The upper row presents the magnetic charge locations calibrated by the one-parameter model, shown using side views of poles P1 and P2. It can be clearly seen that, for the lower pole, some of the magnetic charge locations are located outside the pole. This is because the one-parameter model constrains the magnetic charges to lie along the actuator coordinate axes. The lower row presents the results of the eighteen-parameter model, in which the magnetic charge locations of the lower pole move inside the pole. This is more consistent with the expected physical situation. Moreover, the error histograms shown above also indicate that these magnetic charge locations are more consistent with the theoretical positions.

## Hall-sensor-voltage-based lumped-parameter modeling and calibration

- This figure conveys the sensing concept: the Hall sensor measures the pole's leakage flux. The colour-coded arrows show the flux channelled inside the cone toward the tip, while the dashed arrows around the pole are the part that escapes through the lateral surface and returns through the air. The sensor (green patch) is mounted on that surface, so it sits in the leakage field rather than in the field between the tips, and the red arrow n⁺ marks the positive sense of what it reads (b·n⁺).

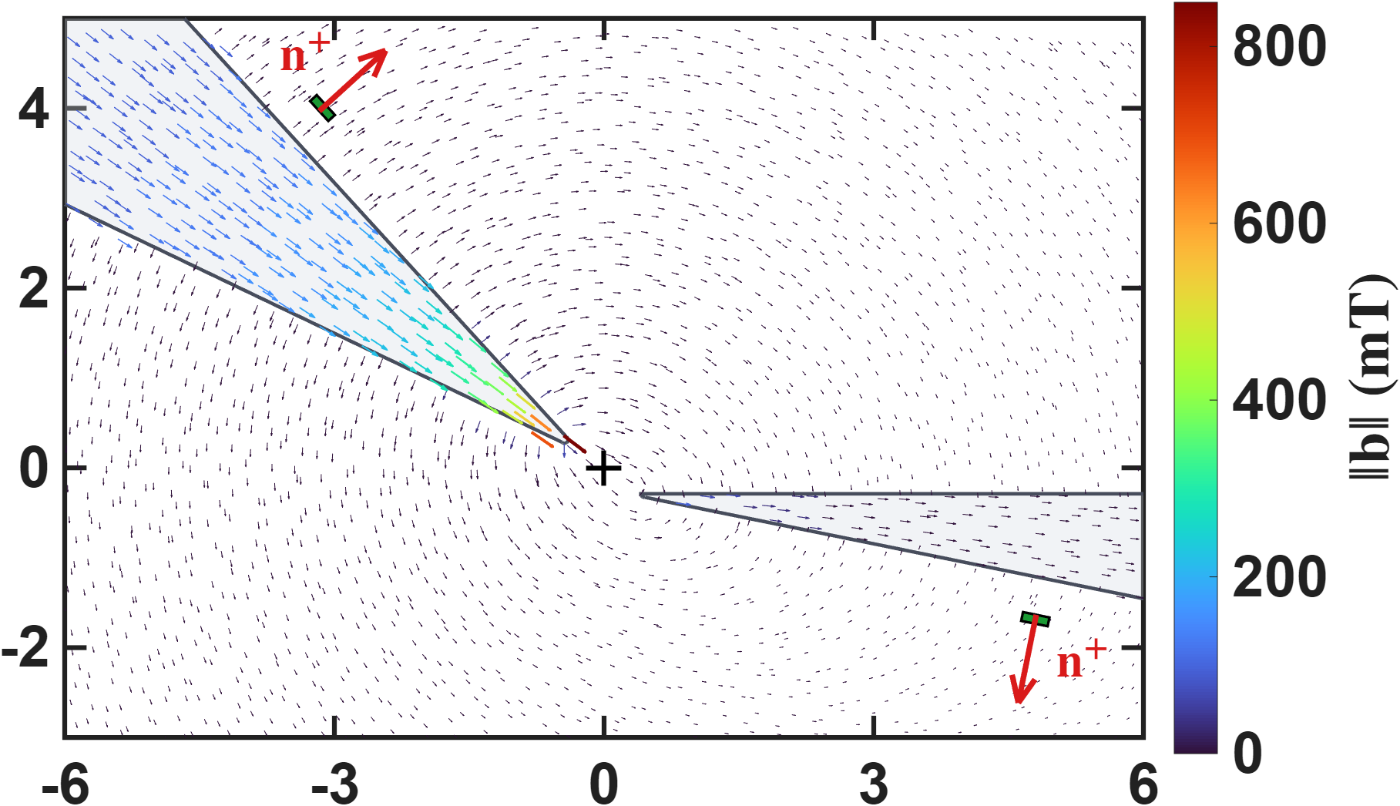
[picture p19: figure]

z−axis(mm)

x−axis(mm)

‖b‖(mT)

## Hall-sensor-voltage-based lumped-parameter modeling and calibration

- Long

Calibrate model→b_(ij) =S_i Bg_V DV_j

NMAE=(∑_j ∑_i ‖b_(ij) −S_i Bg_V DV_j ‖)/(∑_j ∑_i ‖b_(ij) ‖)∙100%=2.81%

z−axis(mm)

3mm

0.41mm

x−axis(mm)

z−axis(mm)

0.41mm

3mm

x−axis(mm)

- Single parameter

D = [0.8333, −0.4701, −0.3324, −0.4255, −0.4318, −0.3290−0.1459, 1.3478, −0.0419, 0.3311, 0.3307, −0.0370−0.3403, −0.4571, 0.8096, −0.4931, −0.4613, −0.34560.0127, 0.4012, −0.1179, 1.4071, 0.3973, −0.00310.0076, 0.3819, −0.0139, 0.3817, 1.3975, −0.1289−0.3337, −0.4360, −0.3366, −0.4378, −0.4911, 0.8320]

ℓ = 870.6 μm Bg_V = 5.0826×10^(−3) mT/mV

- Eighteen parameters

D = [0.8333, −0.4506, −0.1912, −0.3974, −0.4005, −0.1902−0.0121, 1.1706, 0.0025, 0.3536, 0.3563, 0.0030−0.2078, −0.4366, 0.8323, −0.4739, −0.4337, −0.20840.0423, 0.4092, 0.0182, 1.2265, 0.4108, 0.03030.0370, 0.4017, 0.0246, 0.4026, 1.2439, 0.0051−0.2009, −0.4141, −0.1971, −0.4117, −0.4634, 0.8462]

NMAE=(∑_j ∑_i ‖b_(ij) −S_i Bg_V DV_j ‖)/(∑_j ∑_i ‖b_(ij) ‖)∙100%=0.35%

e= [0.0136, 0.0213, −0.1165, 0.0005, −0.0002, −0.1175−0.1142, 0.0019, 0.0199, 0.0187, 0.0002, −0.11620.1150, −0.0025, 0.1157, −0.0012, −0.0112, −0.0178]

ℓ = 867.2 μm Bg_V = 5.9476×10^(−3) mT/mV

V = [1396.4955, −44.8823, −296.1572, −238.4907, −248.9936, −294.5077−52.4055, 1598.7819, −235.7957, −507.9923, −515.0264, −237.7885−294.0025, −233.7070, 1395.0998, −46.3229, −240.9496, −294.4712−235.1370, −531.8974, −51.5603, 1584.0452, −527.8226, −225.8168−241.7433, −521.2460, −229.5170, −520.2282, 1580.6986, −48.3530−287.8722, −243.2083, −296.8820, −235.1671, −44.7058, 1382.8494] (mV)

## Hall-sensor-voltage-based lumped-parameter modeling and calibration

- Long

Calibrate model→b_(ij) =S_i Bg_V DV_j

NMAE=(∑_j ∑_i ‖b_(ij) −S_i Bg_V DV_j ‖)/(∑_j ∑_i ‖b_(ij) ‖)∙100%=2.81%

z−axis(mm)

5mm

0.41mm

x−axis(mm)

0.41mm

5mm

z−axis(mm)

x−axis(mm)

- Single parameter

D = [0.8333, −0.3799, −0.2739, −0.3177, −0.3330, −0.2670−0.2051, 1.2055, −0.0861, 0.2062, 0.2116, −0.0796−0.2707, −0.3315, 0.8164, −0.3881, −0.3414, −0.2777−0.0803, 0.2014, −0.2186, 1.1850, 0.1981, −0.0806−0.0859, 0.1907, −0.0988, 0.1876, 1.1941, −0.2218−0.2585, −0.3162, −0.2651, −0.3089, −0.3816, 0.8273]

ℓ = 870.6 μm Bg_V = 6.6137×10^(−3) mT/mV

- Eighteen parameters

D = [0.8333, −0.3880, −0.1645, −0.3171, −0.3304, −0.1609−0.0895, 1.0485, −0.0584, 0.2272, 0.2342, −0.0556−0.1691, −0.3395, 0.8369, −0.3959, −0.3432, −0.1734−0.0583, 0.2220, −0.0938, 1.0389, 0.2236, −0.0571−0.0651, 0.2181, −0.0708, 0.2171, 1.0694, −0.1021−0.1574, −0.3229, −0.1583, −0.3115, −0.3841, 0.8398]

NMAE=(∑_j ∑_i ‖b_(ij) −S_i Bg_V DV_j ‖)/(∑_j ∑_i ‖b_(ij) ‖)∙100%=0.35%

e= [0.0136, 0.0213, −0.1165, 0.0005, −0.0002, −0.1175−0.1142, 0.0019, 0.0199, 0.0187, 0.0002, −0.11620.1150, −0.0025, 0.1157, −0.0012, −0.0112, −0.0178]

ℓ = 867.2 μm Bg_V = 7.5570×10^(−3) mT/mV

V = [1158.8422, −23.5073, −213.6363, −208.6553, −201.9790, −217.6300−25.8717, 1269.5482, −194.3486, −385.8222, −394.9106, −196.2115−214.4212, −207.6976, 1163.4965, −23.2256, −202.4599, −213.3231−194.6719, −391.3692, −25.8484, 1277.5597, −387.7583, −200.4564−194.2987, −382.7499, −190.9859, −380.5163, 1258.5714, −25.1339−215.1903, −205.8141, −218.6640, −213.0299, −23.0738, 1164.5397](mV)

Moving the sensors further out along the pole flank leaves the field model completely untouched: the effective length, the charge-offset matrix and the fit error are identical to the closer mounting — and identical to the current-based results as well, since both reduce to the same transfer matrix. Only the voltage scale changes: further from the tip the leakage field is weaker, so the measured voltages drop and the voltage gain rises to compensate. This is structural rather than coincidental — the field model is fitted from the workspace field alone, and the sensor geometry enters only afterwards, when the excitation is re-expressed in volts. The predictive accuracy of the model is therefore independent of where the sensor is mounted, and the mounting position becomes a free design choice, bounded in practice only by keeping the sensor voltage within its linear range.

## Hall-sensor-voltage-based lumped-parameter modeling and calibration

- Zhi peng

Calibrate model→b_(ij) =S_i Bg_V DV_j

NMAE=(∑_j ∑_i ‖b_(ij) −S_i Bg_V DV_j ‖)/(∑_j ∑_i ‖b_(ij) ‖)∙100%=10.53%

z−axis(mm)

0.588mm

3mm

x−axis(mm)

3mm

z−axis(mm)

0.588mm

x−axis(mm)

- Single parameter

D = [0.8333, −0.1582, −0.2582, 0.0255, 0.0261, −0.2560−0.1499, 0.8431, 0.0379, −0.2501, −0.2509, 0.0403−0.2577, 0.0249, 0.8309, −0.1615, 0.0235, −0.25900.0407, −0.2494, −0.1523, 0.8432, −0.2503, 0.03950.0396, −0.2493, 0.0383, −0.2502, 0.8435, −0.1504−0.2566, 0.0251, −0.2605, 0.0245, −0.1614, 0.8317]

ℓ = 744.5 μm Bg_V = 8.0294×10^(−3) mT/mV

- Eighteen parameters

D = [0.8333, −0.1783, −0.1746, −0.0627, −0.0627, −0.1743−0.1608, 0.8553, −0.0403, −0.1553, −0.1557, −0.0386−0.1770, −0.0639, 0.8376, −0.1817, −0.0660, −0.1781−0.0393, −0.1562, −0.1611, 0.8583, −0.1558, −0.0398−0.0403, −0.1564, −0.0402, −0.1564, 0.8619, −0.1614−0.1757, −0.0638, −0.1773, −0.0646, −0.1805, 0.8342]

e= [−0.0008, 0.0013, −0.2149, 0.2140, 0.2148, −0.2140−0.2137, 0.2139, 0.0011, 0.0002, 0.2156, −0.21380.2136, −0.2143, 0.2143, −0.2150, 0.0009, −0.0003]

ℓ = 597.6 μm Bg_V = 8.5290×10^(−3) mT/mV

NMAE=(∑_j ∑_i ‖b_(ij) −S_i Bg_V DV_j ‖)/(∑_j ∑_i ‖b_(ij) ‖)∙100%=0.75%

V = [4057.0198, −203.7635, −230.3685, −1019.0765, −1019.5890, −230.5135−236.4145, 3989.6282, −1076.6144, −268.5929, −268.2199, −1080.4810−251.1851, −1066.3534, 3605.6212, −169.1917, −884.8638, −272.1343−1126.6398, −292.2599, −209.1224, 3546.9067, −315.8605, −949.8581−1122.0742, −292.3009, −946.5692, −314.8956, 3537.2584, −208.6201−253.8340, −1067.5789, −272.8701, −888.6158, −171.4135, 3614.5865](mV)

Moving the sensors further out along the pole flank leaves the field model completely untouched: the effective length, the charge-offset matrix and the fit error are identical to the closer mounting — and identical to the current-based results as well, since both reduce to the same transfer matrix. Only the voltage scale changes: further from the tip the leakage field is weaker, so the measured voltages drop and the voltage gain rises to compensate. This is structural rather than coincidental — the field model is fitted from the workspace field alone, and the sensor geometry enters only afterwards, when the excitation is re-expressed in volts. The predictive accuracy of the model is therefore independent of where the sensor is mounted, and the mounting position becomes a free design choice, bounded in practice only by keeping the sensor voltage within its linear range.

## Hall-sensor-voltage-based lumped-parameter modeling and calibration

- Zhi peng

Calibrate model→b_(ij) =S_i Bg_V DV_j

NMAE=(∑_j ∑_i ‖b_(ij) −S_i Bg_V DV_j ‖)/(∑_j ∑_i ‖b_(ij) ‖)∙100%=10.53%

z−axis(mm)

5mm

x−axis(mm)

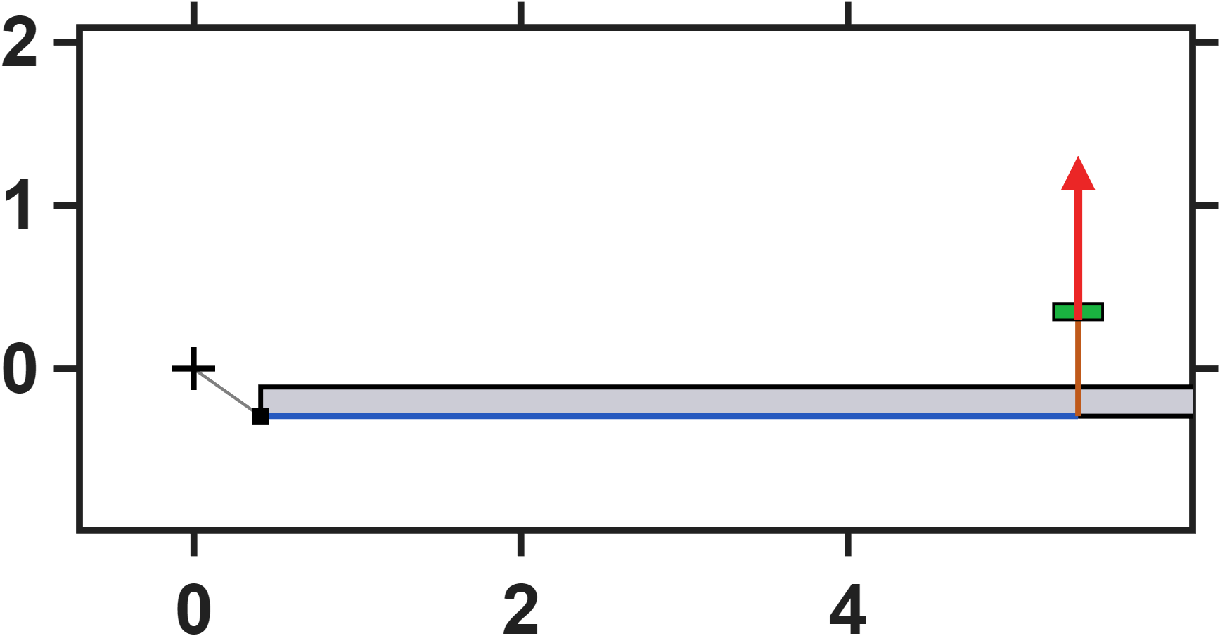
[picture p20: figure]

0.588mm

- Single parameter

D = [0.8333, −0.1619, −0.2723, −0.0000, 0.0012, −0.2707−0.1525, 0.8523, 0.0218, −0.2631, −0.2631, 0.0229−0.2704, 0.0018, 0.8306, −0.1644, 0.0012, −0.27340.0215, −0.2629, −0.1567, 0.8546, −0.2649, 0.02130.0214, −0.2626, 0.0201, −0.2647, 0.8535, −0.1543−0.2710, 0.0020, −0.2752, 0.0011, −0.1657, 0.8324]

ℓ = 744.5 μm Bg_V = 1.0115×10^(−2) mT/mV

- Eighteen parameters

D = [0.8333, −0.1862, −0.1867, −0.0929, −0.0920, −0.1867−0.1654, 0.8667, −0.0579, −0.1628, −0.1627, −0.0577−0.1874, −0.0914, 0.8366, −0.1892, −0.0931, −0.1903−0.0604, −0.1647, −0.1669, 0.8723, −0.1649, −0.0598−0.0605, −0.1648, −0.0599, −0.1653, 0.8744, −0.1669−0.1876, −0.0913, −0.1900, −0.0929, −0.1892, 0.8345]

e= [−0.0008, 0.0013, −0.2149, 0.2140, 0.2148, −0.2140−0.2137, 0.2139, 0.0011, 0.0002, 0.2156, −0.21380.2136, −0.2143, 0.2143, −0.2150, 0.0009, −0.0003]

ℓ = 597.6 μm Bg_V = 1.0769×10^(−2) mT/mV

V = [3194.8553, −117.3275, −144.4692, −690.6945, −693.8828, −143.8277−147.1312, 3117.2840, −763.8698, −181.5529, −181.7863, −761.7138−157.0378, −718.4597, 2844.4753, −97.5260, −592.0820, −176.2582−779.4693, −193.0518, −132.2696, 2757.4837, −217.5690, −657.5762−779.3156, −193.1855, −657.5229, −217.3208, 2755.9319, −132.1218−156.5529, −719.4387, −176.2635, −591.9505, −97.4567, 2846.2025](mV)

Moving the sensors further out along the pole flank leaves the field model completely untouched: the effective length, the charge-offset matrix and the fit error are identical to the closer mounting — and identical to the current-based results as well, since both reduce to the same transfer matrix. Only the voltage scale changes: further from the tip the leakage field is weaker, so the measured voltages drop and the voltage gain rises to compensate. This is structural rather than coincidental — the field model is fitted from the workspace field alone, and the sensor geometry enters only afterwards, when the excitation is re-expressed in volts. The predictive accuracy of the model is therefore independent of where the sensor is mounted, and the mounting position becomes a free design choice, bounded in practice only by keeping the sensor voltage within its linear range.

NMAE=(∑_j ∑_i ‖b_(ij) −S_i Bg_V DV_j ‖)/(∑_j ∑_i ‖b_(ij) ‖)∙100%=0.75%

5mm

z−axis(mm)

0.588mm

x−axis(mm)

## Quantitative Assessment of Multi-Pole Actuators

Setup: The assessment that follows compares two six-pole actuator designs, Design 1 on a circular yoke and Design 2 on a planar square frame. Both are described by the same lumped-parameter model and use the pole numbering P1-P6 shown here.
Sharing the model form and the pole numbering, the two differ only in geometry, so their calibrated parameters can be compared directly in the following slides.

- DesignA


P2

P3

P5

P6

P4

P1

- DesignB


P2

P3

P5

P6

P4

P1

## Quantitative Assessment of Multi-Pole Actuators

- DesignA

- The capacity measure C for Design A is mapped on three mutually orthogonal actuator planes through the origin ( x_a – y_a , x_a – z_a , y_a – z_a ). The model is calibrated on the converged design within R ≤ 150 µm, then evaluated point by point out to the pole-tip sphere at R = 500 µm; the two pole pairs lying in each plane are marked on the rim.
- C peaks on the rim along the pole directions (16.7–17.3 mT/A) and bottoms out on the rim between poles (13.2–13.3), while the centre sits at 14.39 mT/A and is identical on all three planes. Along a pole axis C therefore rises monotonically with radius, but between poles it rises then falls, so the weakest actuation in the workspace lies on the rim between poles rather than at the centre — the centre is the most uniform point, not the weakest. The four lobes are not equal in strength: the lower poles P1/P3/P6 reach ≈16.69 and the upper poles P2/P4/P5 ≈17.32, a 3.8 % difference, and the arrangement of strong lobes differs on x_a – y_a from the other two planes — a direct signature of the upper/lower asymmetry of Long's half-cut geometry.

P3

Capacity measure ((mT)/A)

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
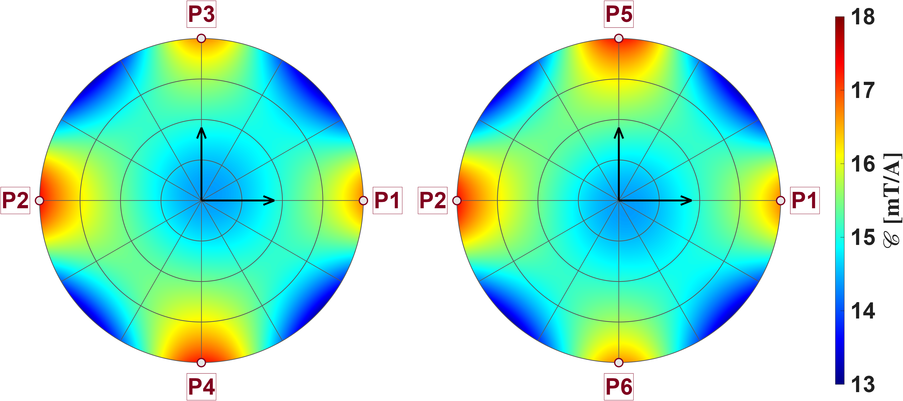
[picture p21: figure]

Capacity measure ((mT)/A)

z_a

P5

P4

y_a

P3

P6

## Quantitative Assessment of Multi-Pole Actuators

- DesignA

- Same three actuator planes and the same calibrated model as the previous slide, now mapping isotropy κ = σ₃/σ₁ (dimensionless, colour scale 0–1). It is again evaluated point by point out to the pole-tip sphere at R = 500 µm, with the in-plane pole pairs marked on the rim.
- κ is close to 1 at the centre and decays outwards, staying above 0.8 roughly within the calibration radius of 150 µm before degrading quickly. The decay is not circularly symmetric: at the rim, isotropy is worst along the pole directions and best between poles, differing by about a factor of two. Isotropy is therefore the exact complement of capacity — the rim along a pole axis, where the gain is largest, is where the isotropy is worst. The upper poles reach a slightly lower minimum than the lower poles, consistent with the half-cut asymmetry seen on the previous slide. All three planes look essentially the same, showing that the isotropy inherits the overall symmetry of the six-pole layout.

P3

P5

P2

y_a

P2

Isotropy

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
Isotropy

y_a

P3

P6

## Quantitative Assessment of Multi-Pole Actuators

- DesignA

- Using the same calibrated model, the three singular values σ₁ ≥ σ₂ ≥ σ₃ at every real FEM node in the workspace are histogrammed separately All three share one set of bins and are each normalised to a percentage, so the bar heights are directly comparable.Both histograms have the same resolution (0.02mT/A).
- Within the calibration radius Design A behaves as an essentially direction-independent three-degree-of-freedom actuator: the three principal gains differ by only 13.5 %, no direction is weak enough to be unusable, and the controller needs no extra margin for any particular axis. What sets the usable authority is the weakest axis σ₃, whose mean is 13.85 mT/A with only 1.5 % variation — the worst-case actuation capability is therefore very nearly a constant across the whole workspace and can be taken directly as a design value. Almost all of the spread comes from the strongest axis σ₁ (3.7 % variation), but since performance is governed by the weakest axis this fluctuation does not affect the guaranteed capability. The three peaks are clearly separated yet all fall within the narrow band of 13.4–17.3 mT/A, overlapping only on their adjacent flanks — direct evidence that the hexapole remains well-conditioned at this radius.

Capacity measure ((mT)/A)

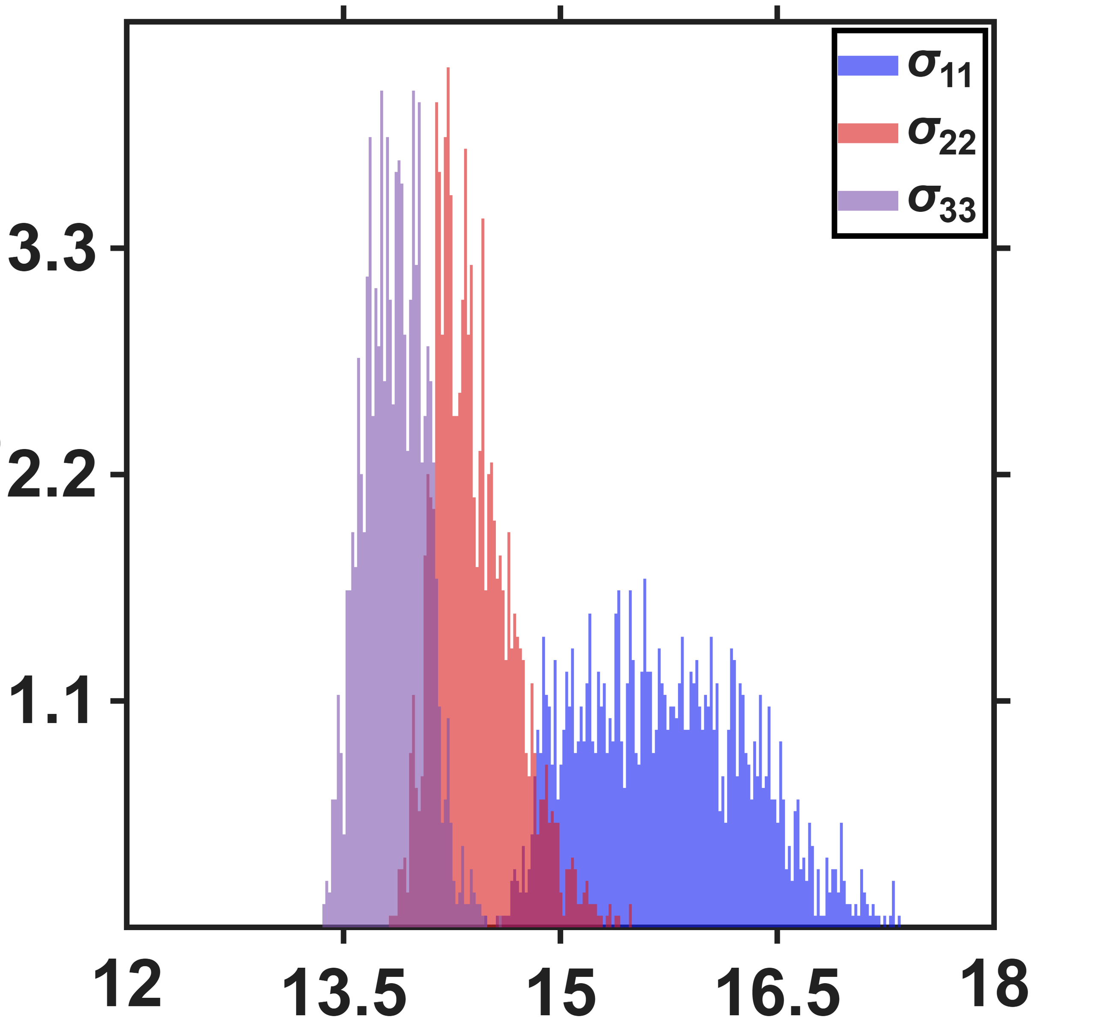
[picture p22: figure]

Percentage count (%)

| σ_11 | σ_22 | σ_33
Mean ((mT)/(A)) | 15.722 | 14.403 | 13.852

## Quantitative Assessment of Multi-Pole Actuators

- DesignA

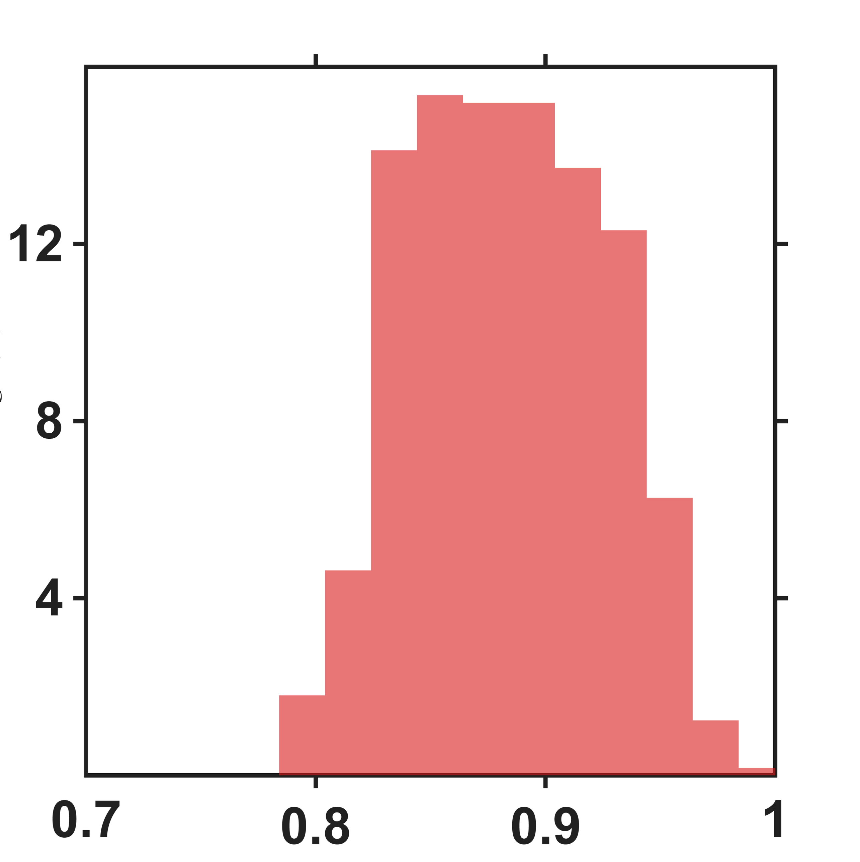
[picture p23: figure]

Percentage count (%)

Isotropy

- Histogram resolution:0.02

Mean ((mT)/(A)) | 0.8836

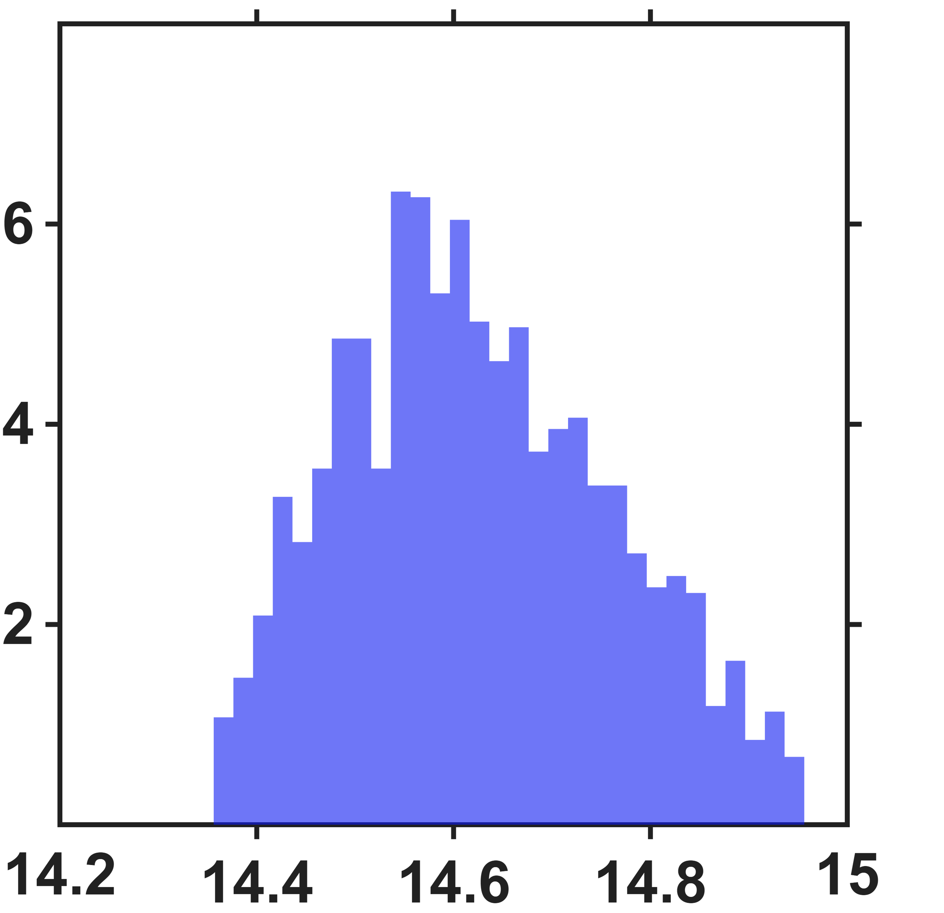
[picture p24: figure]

Capacity measure ((mT)/A)

Percentage count (%)

- Histogram resolution:0.02 mT/A

Mean ((mT)/(A)) | 14.6246

## Quantitative Assessment of Multi-Pole Actuators

- DesignA

Capacity measure ((mT)/A)

Percentage count (%)

Percentage count (%)

Isotropy

- Histogram resolution:0.02 mT/A

Mean ((mT)/(A)) | 14.6246

- Histogram resolution:0.02

Mean ((mT)/(A)) | 0.8836

## Quantitative Assessment of Multi-Pole Actuators

- DesignB

- The capacity measure C for Design B is mapped on the same three actuator planes, with a colour scale of 30–55 mT/A. The model is calibrated on the converged design within R ≤ 150 µm and evaluated point by point out to the pole-tip sphere at R = 500 µm, with the in-plane pole pairs marked on the rim.
- The spatial pattern matches Design A: the centre sits mid-range at about 38 mT/A, C rises monotonically along a pole axis to a maximum of about 51 on the rim, and falls to about 31 on the rim between poles, a directional variation of roughly 1.6× at the outer edge. The overall level is about 2.6× that of Design A (37.96 vs 14.39 mT/A at the centre), and this ratio holds across radii and directions, so the gain is raised as a whole rather than the field shape being altered. One difference from Design A is that the six lobes are nearly equal in strength (50.6–51.1 mT/A, about 1 % spread), with no splitting into upper and lower groups — a consequence of the planar hexapole's up–down symmetry.

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
Capacity measure ((mT)/A)

P5

P4

z_a

P3

y_a

P6

Capacity measure ((mT)/A)

## Quantitative Assessment of Multi-Pole Actuators

- DesignB

- Isotropy κ for Design B is mapped on the same three actuator planes, with a colour scale of 0–0.8. The model is calibrated on the converged design within R ≤ 150 µm and evaluated point by point out to the pole-tip sphere at R = 500 µm, with the in-plane pole pairs marked on the rim.
- Design B is markedly less isotropic than Design A across the whole workspace: κ at the centre is only 0.54 against 0.95 for Design A. The shape of the distribution also differs — the high- κ region is not a concentric core about the origin but two off-centre lobes along a diagonal, with the best values of 0.60–0.65 occurring roughly 130–175 µm from the centre, only slightly above the 0.54 found at the centre itself. The decay with radius is faster as well, reaching 0.06–0.24 at the rim, with the lowest values along the pole directions. Taken together with the previous slide, the planar hexapole trades isotropy for roughly 2.6× the gain: actuation is stronger overall, but the three principal axes are less balanced and there is no simple "stay at the centre" strategy for best conditioning.

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
Isotropy

P5

z_a

P4

y_a

P3

P6

Isotropy

## Quantitative Assessment of Multi-Pole Actuators

- Using the same calibrated model for Design B, the three singular values σ₁ ≥ σ₂ ≥ σ₃ at every real FEM node in the workspace are histogrammed separately (in mT/A), sharing one set of bins (0.1mT/A wide) and each normalised to a percentage. Note that this bin width differs from the Design A histogram, so bar heights are comparable among the three series here but not across the two slides.
- The three distributions fall into two clear groups: σ₁ and σ₂ sit close together while σ₃ averages just 27.1 mT/A and is separated from the other two by a gap containing no samples at all. The controllable set is therefore an oblate ellipsoid — two comparable strong axes and one distinctly weaker axis — rather than a near-sphere, matching the imbalance of σ₁/σ₃ ≈ 1.85. The usable authority is set by the weakest axis: σ₃ ≈ 27.1 mT/A is still about twice the weakest axis of Design A (13.9 mT/A), so despite the poorer directional balance Design B remains stronger in its worst direction. The cost is slightly less positional stability, σ₃ varying by 5.6 % across the workspace against 1.5 % for Design A.

| σ_11 | σ_22 | σ_33
Mean ((mT)/(A)) | 50.196 | 45.304 | 27.105

- DesignB

Capacity measure ((mT)/A)

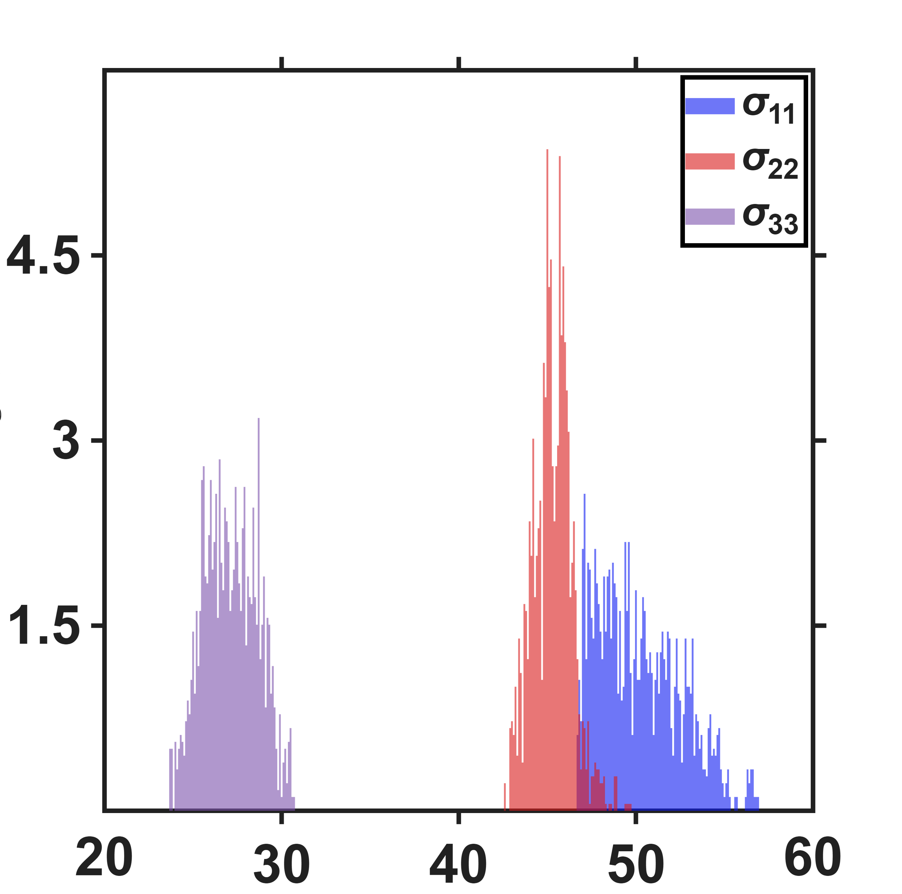
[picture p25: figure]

Percentage count (%)

## Quantitative Assessment of Multi-Pole Actuators

- DesignB

Capacity measure ((mT)/A)

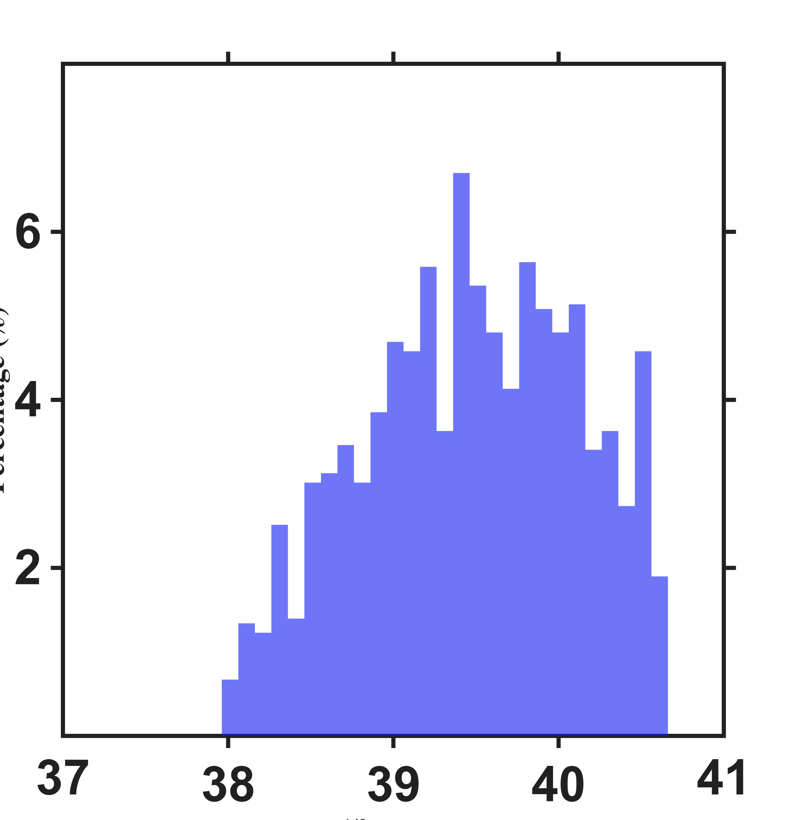
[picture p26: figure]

Percentage count (%)

Percentage count (%)

Isotropy

- Histogram resolution:0.02

Mean ((mT)/(A)) | 0.5415

- Histogram resolution:0.1 mT/A

Mean ((mT)/(A)) | 39.4683

## Quantitative Assessment of Multi-Pole Actuators

- DesignB(Have gap)

- Design B with a 100 µm gap(The air gap is located at the junction between the six guide posts and the magnetic poles.): the capacity measure C on the same three actuator planes, colour scale 18–33 mT/A. The model is calibrated on the converged design within R ≤ 150 µm and evaluated point by point out to the pole-tip sphere at R = 500 µm.
- The spatial pattern is identical to the no-gap case: the centre sits mid-range at 23.1 mT/A, C rises along each pole axis to 30.3–30.8 at the rim, and falls to about 19.5–20.7 on the rim between poles, with the six lobes still nearly equal. Only the overall level changes — the centre drops from 37.96 to 23.08 mT/A and the rim maximum from about 51 to about 31, roughly 0.61× the no-gap design throughout. The gap therefore reduces the gain itself while leaving the field shape and its directional character unchanged.

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

Capacity measure ((mT)/A)

P5

P4

z_a

y_a

P3

P6

Capacity measure ((mT)/A)

y_a

z_a

x_a

x_a

## Quantitative Assessment of Multi-Pole Actuators

- DesignB(Have gap)

- The same gap calibration, now mapping isotropy κ = σ₃/σ₁ on a colour scale of 0–0.8, over the same evaluation range as the previous slide.
- The isotropy pattern also matches the no-gap case: the high- κ region is again offset from the origin and split into two diagonal lobes, with best values of 0.56–0.61 at roughly 160–215 µm from the centre, while the centre itself is 0.46; the rim falls to 0.06–0.27, lowest along the pole directions. Compared with the no-gap design, κ is slightly lower everywhere and the bright lobes sit a little further out. The gap's main cost therefore remains the gain, which drops to 0.61×, while isotropy degrades only modestly and the characteristic that the best-conditioned point is not the origin is unchanged.

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

Isotropy

P5

z_a

P4

y_a

P3

P6

Isotropy

## Quantitative Assessment of Multi-Pole Actuators

- Design B with the gap: the three singular values σ₁ ≥ σ₂ ≥ σ₃ at every real FEM node in the workspace, histogrammed separately on one shared set of bins 0.05mT/A wide, each normalised to a percentage. This bin width differs from the other slides, so bar heights are comparable only among the three series here.
- The structure matches the no-gap case and still falls into two groups: σ₁ and σ₂ average 32.3 and 27.6 mT/A while σ₃ is only 15.5 mT/A, separated from the other two by a gap containing no samples, so the controllable set remains an oblate ellipsoid. The imbalance is somewhat worse, however — σ₁/σ₃ rises from 1.85 without the gap to 2.08, the σ₁–σ₂ separation widens from 10.8 % to 17.2 %, and their overlap nearly vanishes. The weakest axis σ₃ drops to 0.57× its no-gap value but still exceeds Design A's 13.9 mT/A, so even with the gap the planar hexapole retains more authority in its worst direction than the conical one.

- DesignB(Have gap)

Capacity measure ((mT)/A)


Percentage count (%)

| σ_11 | σ_22 | σ_33
Mean ((mT)/(A)) | 32.34 | 27.588 | 15.54

## Quantitative Assessment of Multi-Pole Actuators

- DesignB(Have gap)

Capacity measure ((mT)/A)


Percentage count (%)

Percentage count (%)

Isotropy

- Histogram resolution:0.02

Mean ((mT)/(A)) | 0.4820

- Histogram resolution:0.05mT/A

Mean ((mT)/(A)) | 23.9991
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

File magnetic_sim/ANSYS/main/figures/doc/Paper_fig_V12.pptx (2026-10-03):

## A Lumped-Parameter Modeling, Calibration, and Capacity-Measure Framework for Flux Generation in Symmetric Multipole Electromagnetic Actuators

## Current-based lumped-parameter modeling and calibration

E. Validation

- Interpolation Point Algorithm for sensor area

1. Input N_a ， These represent the numbers of divisions required along the three actuation axes (x_a ,y_a ,z_a )
2. Divided along its three actuation axes according to the following .
→R[1/(N_a) (−1)/(N_a), 0 0, 0, 0 0 0, 1/(N_a)(−1)/(N_a), 0, 0 0 0, 0 0, 1/(N_a), (−1)/(N_a) ]
with an additional center point
Therefore, the total number of points is
N_(tot) (N_a )=1+6N_a
3. Load the FEM data and filter out the air nodes.

4. Localization: Determine which tetrahedron contains each query point and return its coordinates relative to the four vertices.
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

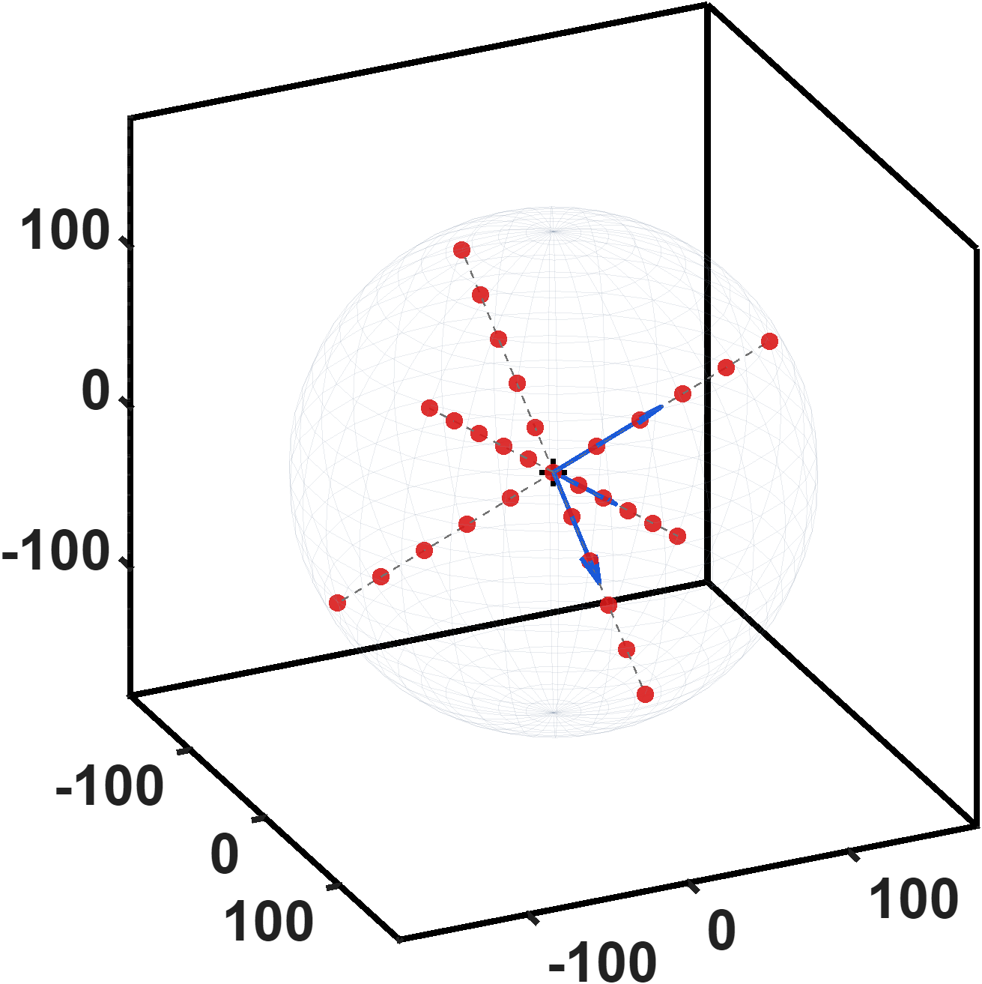
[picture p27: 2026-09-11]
magnetic_sim/ANSYS/main/figures/paper_fig/Section2_E/sphere_grid_3d_R150_as31.png

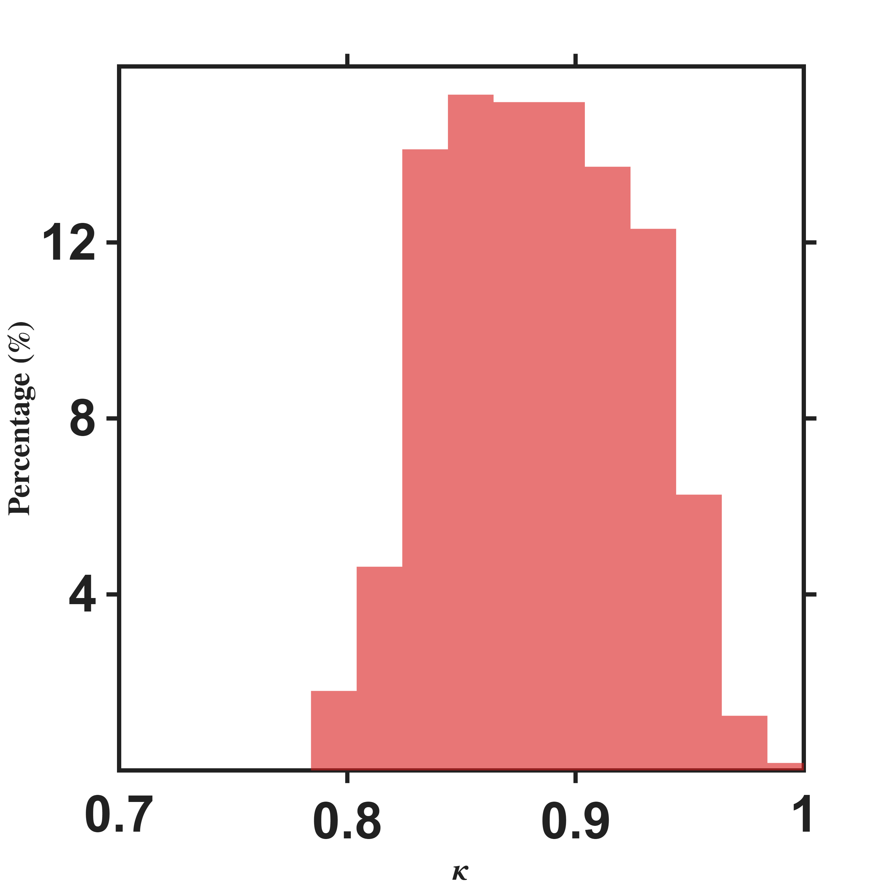
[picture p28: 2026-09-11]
magnetic_sim/ANSYS/main/figures/paper_fig/Section4_C/iso_hist_A_single_R150.png

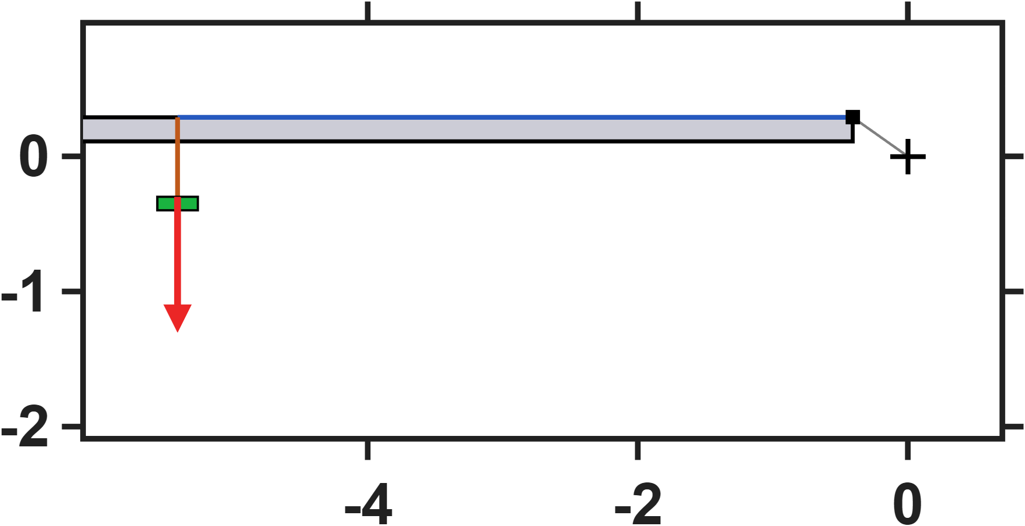
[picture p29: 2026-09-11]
magnetic_sim/ANSYS/main/figures/paper_fig/Section3_A/sensor_mounting_zhi_P2_soff5mm.png

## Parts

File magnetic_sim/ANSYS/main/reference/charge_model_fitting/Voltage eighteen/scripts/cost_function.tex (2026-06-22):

\documentclass[12pt]{article}
\usepackage[a4paper,margin=2cm]{geometry}
\usepackage{amsmath,amssymb}
\usepackage{bm}

\begin{document}
\thispagestyle{empty}

\noindent
\textbf{Cost function (Hall-sensor-based, after eliminating $\bm{d}$):}

\begin{equation*}
\mathrm{cost} \;\Rightarrow\; J(\hat{\ell}) \;=\;
\sum_{j=1}^{N_I}\left[\,
\sum_{i=1}^{N_p}\mathbf{b}_{ij}^{T}\mathbf{b}_{ij}
\;-\;
\left(\sum_{i=1}^{N_p}\mathbf{V}_{j}^{T}\mathbf{S}_{i}^{T}\mathbf{b}_{ij}\right)^{\!T}
\left(\sum_{i=1}^{N_p}\mathbf{V}_{j}^{T}\mathbf{S}_{i}^{T}\mathbf{S}_{i}\mathbf{V}_{j}\right)^{\!-1}
\left(\sum_{i=1}^{N_p}\mathbf{V}_{j}^{T}\mathbf{S}_{i}^{T}\mathbf{b}_{ij}\right)
\right]
\end{equation*}

\end{document}

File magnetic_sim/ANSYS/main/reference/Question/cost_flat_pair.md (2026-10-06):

# 對極結構單一激發、中心取樣時，cost 曲線在 ℓ̂ 大的一側變平

狀態：**待討論**（2026-10-06）。來源：組會簡報 `report/406/10.6/10.pptx` 第 3、4 頁。

## 1. 觀察

### 1.1 之前的對極三維校正（簡報第 3 頁，志鵬 Pair_pole）

- 場：`D:\Maxwell_sim\Zhi_peng\export\Pair_pole\{P1,P2}.fld`。
- 取樣：原點＝兩極尖中點，沿致動軸 xa（斜 35.26°）取 2·Nr+1 = 11 點（±150 µm、間距 30 µm），三維場。
- 模型：兩顆電荷 p̄c1 = û + ê1、p̄c2 = û + ê2，約束 ê1u − ê2u = 0；bᵢ(p) = Sᵢ·G，S 兩欄（兩顆電荷），G 閉式消去，
  min J(ℓ̂, ê, G) = Σbᵢᵀbᵢ − (ΣSᵢᵀbᵢ)ᵀ(ΣSᵢᵀSᵢ)⁻¹(ΣSᵢᵀbᵢ)。
- ℓ̂ 輪廓（固定 ℓ̂、重擬 ê，J/J_min，ℓ̂ = 500 ~ 856 µm）：

| | ℓ̂ | J/J_min @ 500 µm | J/J_min @ 856 µm |
|---|---|---|---|
| 一個激發（P1） | 678.4764 µm | 11.6 | **1.18**（高側幾乎平） |
| 兩個激發（P1、P2） | 623.5410 µm | 6.76 | 4.16 |

### 1.2 一維模型重做（簡報第 4 頁，NTU）

- 模型：H(x) = a·I/(x − ℓ̂)²，資料 |b_x|/I，給定 ℓ̂ 時 a 閉式，對 ℓ̂ 掃描得 profile cost J(ℓ̂)。
- 取樣：比照第 3 頁「中心取樣」，但軸線改水平——以極尖前 500 µm 為中心、±150 µm、17 點（x = −650 ~ −350 µm）。

| 配置 | 激發 | ℓ̂ | cost 曲線 |
|---|---|---|---|
| 單極 | P1 | 416.9 µm | 有明確極小值 |
| 對極（左極尖在 −1000 µm、同軸） | 只激發 P1 | 1560.5 µm | 由 ℓ̂ = 0 單調下降後**平坦**，J ≤ 1.1 J_min 的範圍 1348 ~ 1829 µm |

對照（簡報第 2 頁，取樣貼近極尖 x = −340 ~ −20 µm）：單極 ℓ̂ = 103.5 µm、對極 ℓ̂ = 123.0 µm，兩者都有明確極小值。

## 2. 問題

cost 曲線在 ℓ̂ 大的一側變平，目前只在下面三個條件**同時**成立時出現：

1. 對極結構（另一顆極存在）；
2. 只激發其中一顆極；
3. 取樣點在兩極中間（離被激發極尖遠），而不是貼近極尖。

為什麼？是資料本身（對極的場在中間區域的形狀）造成，還是模型數學（ℓ̂ 與 a、ê、G 的可辨識性）造成，或兩者皆有？

## 3. 可考慮的方向

- 未激發的那顆極是導磁的回流路徑：兩極中間的場是「被激發極 + 另一極回流」的疊加，沿軸的衰減可能比單一點電荷 1/d² 慢，單電荷模型只能用很大的 ℓ̂ 去配平緩的場。
- 可辨識性：取樣點離電荷越遠、取樣範圍相對距離越窄，1/d² 越接近一段緩坡，ℓ̂ 與 a（或 G）的敏感度越共線，谷底越平。
- 第二個激發：兩個激發時曲線兩側都被夾住（第 3 頁紅線），代表第二筆場資料提供了單一激發缺少的約束；待確認一維模型是否有同樣現象。
- 分開驗證：沿整條軸看單一激發的場形狀（最小值位置、局部衰減率），以及只改一個條件（排列、激發數、取樣位置）時曲線如何變。

## 4. 相關檔案（`matlab/Flux/Maxwell/` 下）

| 內容 | 腳本 | 資料 | 圖 |
|---|---|---|---|
| NTU 一維取樣與擬合 | `utils/scripts/NTU_hexapole/{sp_axis_calc,pp_axis_calc,sp_axis_fit}.m` | `utils/data/NTU_hexapole/{sp,pp}_axis[_c500].mat` | `figures/NTU_hexapole/{single_pole,pair_pole}/sampling[_c500].png` |
| NTU profile cost | `utils/scripts/NTU_hexapole/sp_cost_b.m`（`CASE`、`SAMP`） | `utils/data/NTU_hexapole/{sp,pp}_cost_b[_c500].mat` | `figures/NTU_hexapole/{single_pole,pair_pole}/cost_b[_c500].png` |
| NTU 殘差（擬合 vs FEM） | `plot/NTU_hexapole/current/sp_axis_plot.m` | `{sp,pp}_axis.mat` | `figures/NTU_hexapole/{single_pole,pair_pole}/b_axis.png` |
| 志鵬對極取樣、一維擬合 | `utils/scripts/zhi_peng/{zp_axis_fit,zp_slice_y0}.m`、`plot/zhi_peng/{pair_sampling,pair_field_xa}.m` | `utils/data/zhi_peng/zp_*.mat` | `figures/zhi_peng/pair_pole/*.png` |
| 志鵬對極三維輪廓（第 3 頁） | 10-01 的 `fitting_pair.m` 已於 10-03 刪除 | — | `figures/zhi_peng/pair_profile.png` |

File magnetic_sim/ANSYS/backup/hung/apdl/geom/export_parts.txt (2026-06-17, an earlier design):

! Export all simulation parts as individual IGES (SolidWorks units)
! Output to magnetic_sim/hung/IGES/
/CWD,'C:\Users\pmero\Documents\Lab406\FEM_sim\magnetic_sim\hung\IGES'

! ============================================================
! Part 1: Mag_Pole_Bottom (D-shape pole along +X axis)
! ============================================================
/CLEAR, NOSTART
/PREP7
*afun, DEG
MM = 1.0/25.4

POLE_R         = 3.175*MM
POLE_CONE_LEN  = 15.875*MM
POLE_TOTAL_LEN = 43.0*MM
POLE_FLAT_LEN  = 28.0*MM

! Tip at origin, axis = +X, side_perp = +Y
! Front section (D-shape, 0~28mm): VROTAT 180°
K, 1, 0, 0, 0                                          ! tip
K, 2, POLE_CONE_LEN, POLE_R, 0                         ! cone-cyl junction
K, 3, POLE_FLAT_LEN, POLE_R, 0                         ! flat cut boundary
K, 4, POLE_FLAT_LEN, 0, 0                              ! flat cut boundary (axis)
K, 5, POLE_TOTAL_LEN, 0, 0                             ! far end (axis)

L, 1, 2
L, 2, 3
L, 3, 4
L, 4, 1
AL, 1, 2, 3, 4
VROTAT, 1, ,,,, , 1, 5, 180, 2

ALLSEL, ALL

! Back section (full round, 28~43mm): VROTAT 360°
*get, KP_NUM, KP, , NUM, MAX
KS = KP_NUM + 1
NUMSTR, KP, KS
*get, LI_NUM, LINE, , NUM, MAX
LS = LI_NUM + 1
NUMSTR, LINE, LS

K, KS,   POLE_FLAT_LEN, 0, 0
K, KS+1, POLE_FLAT_LEN, POLE_R, 0
K, KS+2, POLE_TOTAL_LEN, POLE_R, 0
K, KS+3, POLE_TOTAL_LEN, 0, 0

L, KS, KS+1
L, KS+1, KS+2
L, KS+2, KS+3
L, KS+3, KS

*get, AR_NUM, AREA, , NUM, MAX
AS = AR_NUM + 1
NUMSTR, AREA, AS
AL, LS, LS+1, LS+2, LS+3
VROTAT, AS, ,,,, , KS, KS+3, , 4

ALLSEL, ALL
IGESOUT, 'Mag_Pole_Bottom', 'iges'
*msg, INFO
 Part 1: Mag_Pole_Bottom exported

! ============================================================
! Part 2: Pole_Block_Top (upper block, L-shape, 25x22x10mm)
! ============================================================
/CLEAR, NOSTART
/PREP7
*afun, DEG
MM = 1.0/25.4
BLK_T = 10.0*MM

! L-shape cross-section in XY plane, extrude along Z
! Part1: X [-0.25, 12.75], Y [-11, 11] mm (main body)
! Part2: X [-12.25, -0.25], Y [-5, 5] mm (extension)
BLOCK, -0.25*MM, 12.75*MM, -11*MM, 11*MM, 0, BLK_T
BLOCK, -12.25*MM, -0.25*MM, -5*MM, 5*MM, 0, BLK_T

*get, V2, VOLU, 0, NUM, MAX
VADD, V2-1, V2

ALLSEL, ALL
IGESOUT, 'Pole_Block_Top', 'iges'
*msg, INFO
 Part 2: Pole_Block_Top exported

! ============================================================
! Part 3: Pole_Block_Bottom (lower block, L-shape, 22x22x10mm)
! ============================================================
/CLEAR, NOSTART
/PREP7
*afun, DEG
MM = 1.0/25.4
BLK_T = 10.0*MM

! Part1: X [2, 9], Y [-11, 11] mm
! Part2: X [-13, 2], Y [-5, 5] mm
BLOCK, 2*MM, 9*MM, -11*MM, 11*MM, 0, BLK_T
BLOCK, -13*MM, 2*MM, -5*MM, 5*MM, 0, BLK_T

*get, V2, VOLU, 0, NUM, MAX
VADD, V2-1, V2

ALLSEL, ALL
IGESOUT, 'Pole_Block_Bottom', 'iges'
*msg, INFO
 Part 3: Pole_Block_Bottom exported

! ============================================================
! Part 4: Mag_Guide_Post (cylinder R=4mm, H=41mm)
! ============================================================
/CLEAR, NOSTART
/PREP7
*afun, DEG
MM = 1.0/25.4

CYL4, 0, 0, 4.0*MM, 0, , 360, 41.0*MM

ALLSEL, ALL
IGESOUT, 'Mag_Guide_Post', 'iges'
*msg, INFO
 Part 4: Mag_Guide_Post exported

! ============================================================
! Part 5: Coil (ring R_in=10, R_out=12, H=15mm)
! ============================================================
/CLEAR, NOSTART
/PREP7
*afun, DEG
MM = 1.0/25.4

CYL4, 0, 0, 10.0*MM, 0, 12.0*MM, 360, 15.0*MM

ALLSEL, ALL
IGESOUT, 'Coil', 'iges'
*msg, INFO
 Part 5: Coil exported

! ============================================================
! Part 6: Mag_Iron_Ring (yoke R_in=38, R_out=62.5, T=2mm)
! ============================================================
/CLEAR, NOSTART
/PREP7
*afun, DEG
MM = 1.0/25.4

CYL4, 0, 0, 38.0*MM, 0, 62.5*MM, 360, 2.0*MM

ALLSEL, ALL
IGESOUT, 'Mag_Iron_Ring', 'iges'
*msg, INFO
 Part 6: Mag_Iron_Ring exported

FINISH

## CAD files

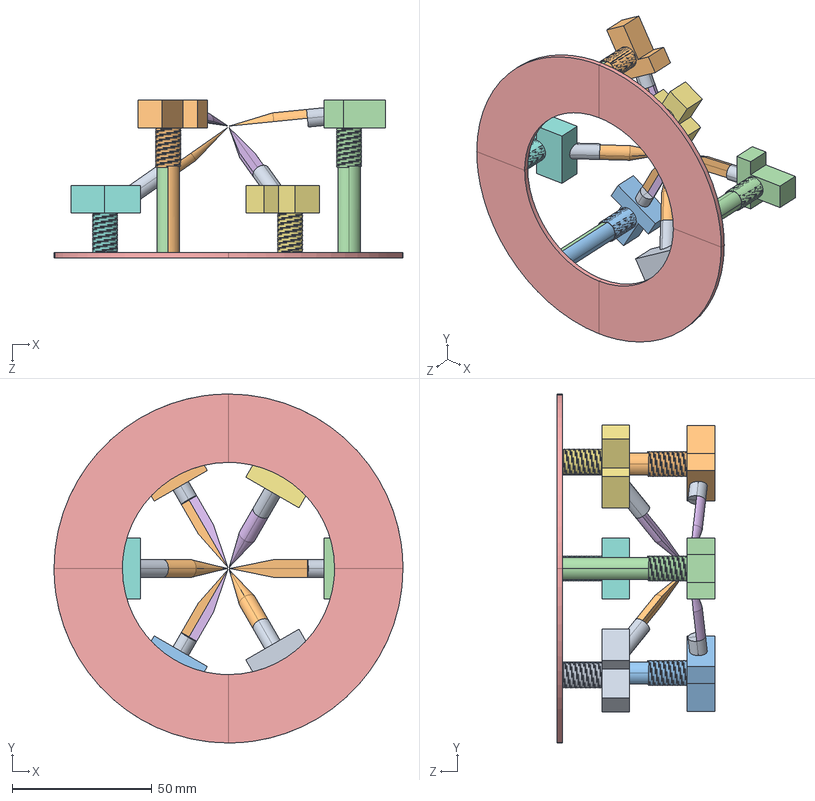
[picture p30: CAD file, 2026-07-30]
magnetic_sim/ANSYS/main/CAD_model/hung_hexapole/STEP/full_assembly_coil.STEP
125.0 x 125.0 x 56.5 mm

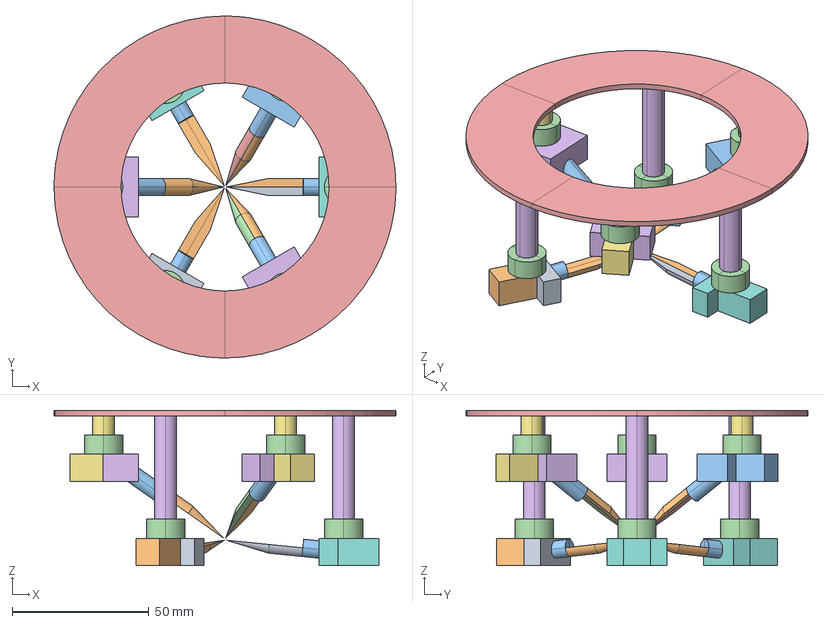
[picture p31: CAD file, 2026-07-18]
magnetic_sim/ANSYS/main/model_check/hung_hexapole/hung_full_assembly_R700.step
125.0 x 125.0 x 56.7 mm

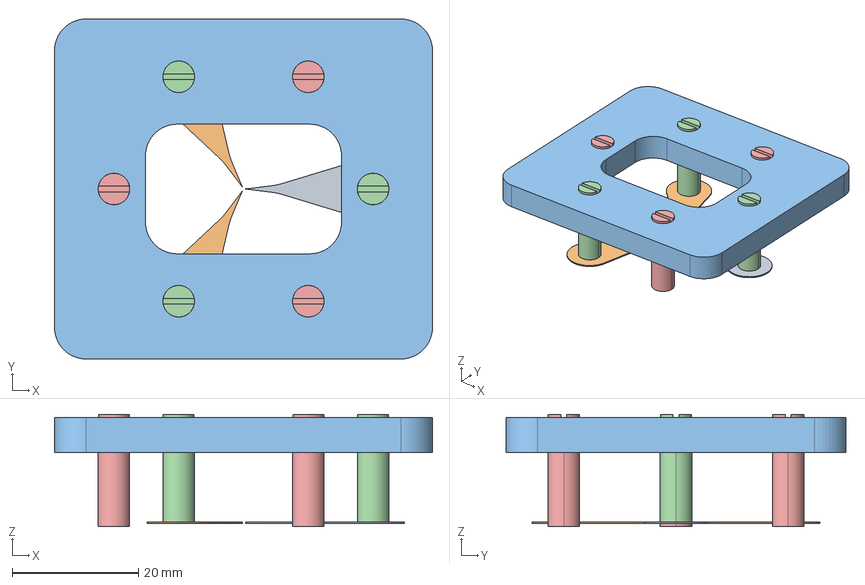
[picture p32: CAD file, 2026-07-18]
magnetic_sim/ANSYS/main/model_check/NTU_hexapole/upper_assembly.step
59.8 x 53.8 x 17.8 mm

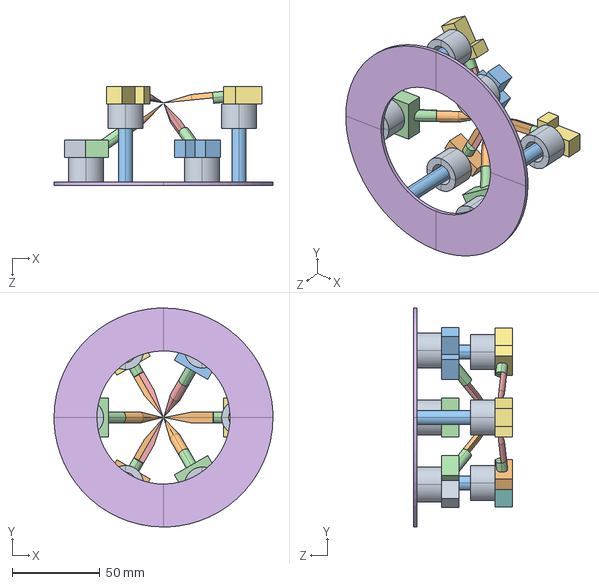
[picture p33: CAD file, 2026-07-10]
magnetic_sim/ANSYS/main/CAD_model/hung_hexapole/STEP/Full_Assembly.STEP
125.0 x 125.0 x 56.5 mm

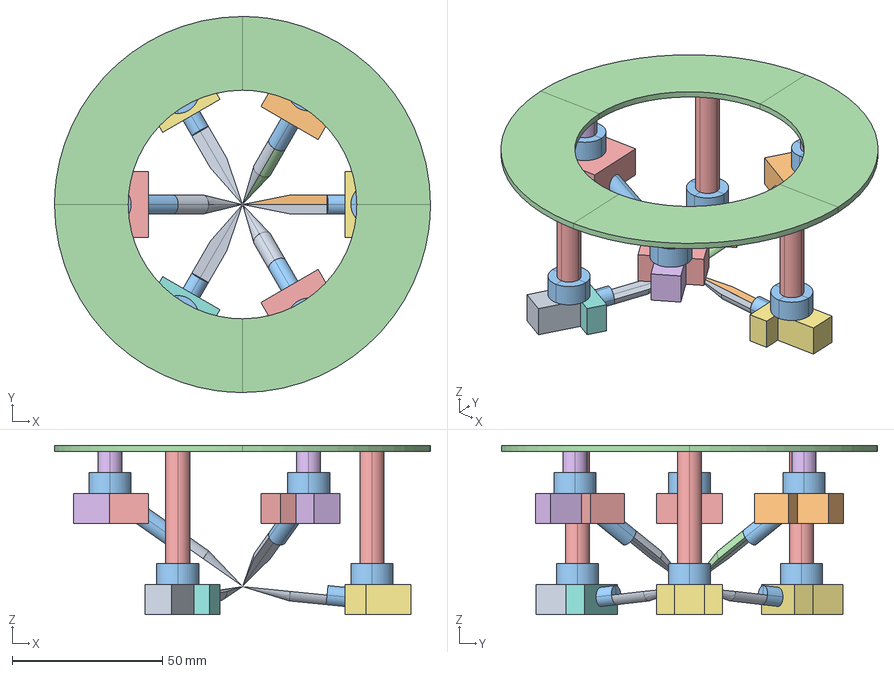
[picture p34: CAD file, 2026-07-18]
magnetic_sim/ANSYS/main/model_check/hung_hexapole/hung_full_assembly_R300.step
125.0 x 125.0 x 56.3 mm

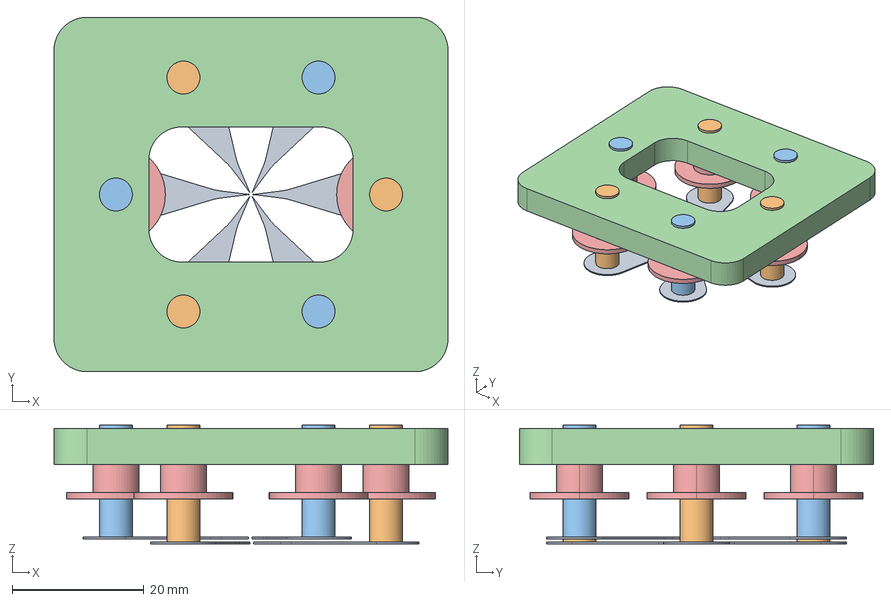
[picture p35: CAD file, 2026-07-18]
magnetic_sim/ANSYS/main/model_check/NTU_hexapole/full_assembly.step
59.8 x 53.8 x 18.0 mm

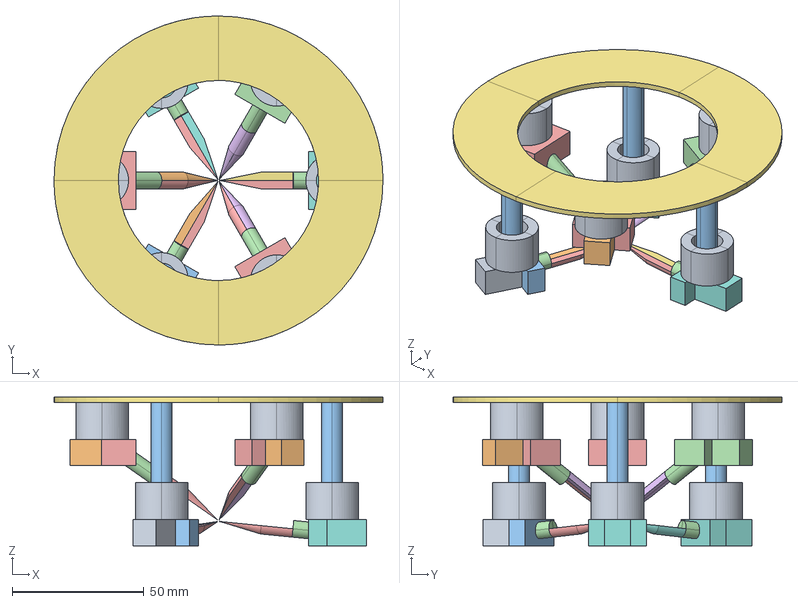
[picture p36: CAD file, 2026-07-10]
magnetic_sim/ANSYS/main/model_check/hung_hexapole/hung_hexapole_full.iges
125.0 x 125.0 x 56.5 mm

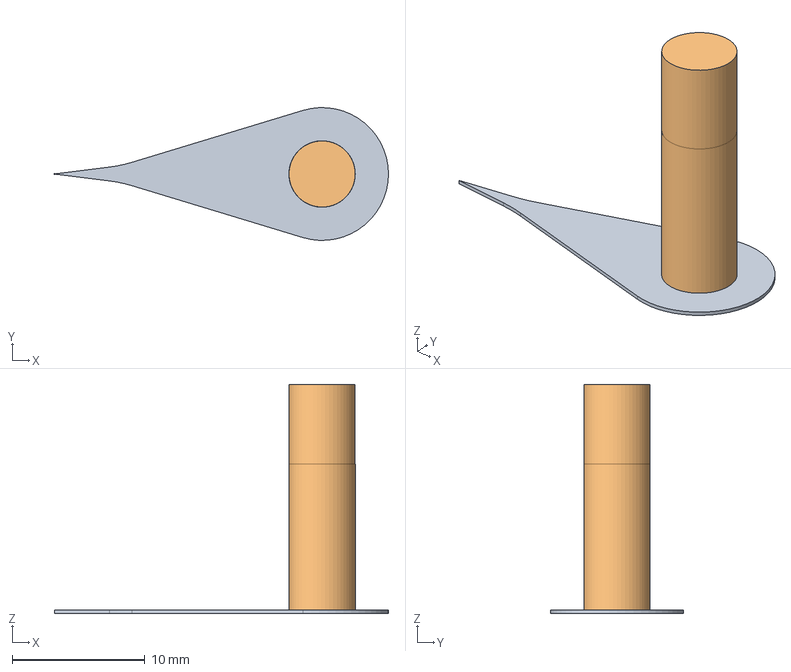
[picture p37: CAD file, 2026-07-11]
magnetic_sim/ANSYS/main/model_check/NTU_hexapole/pole_assembly.step
25.1 x 9.99 x 17.2 mm

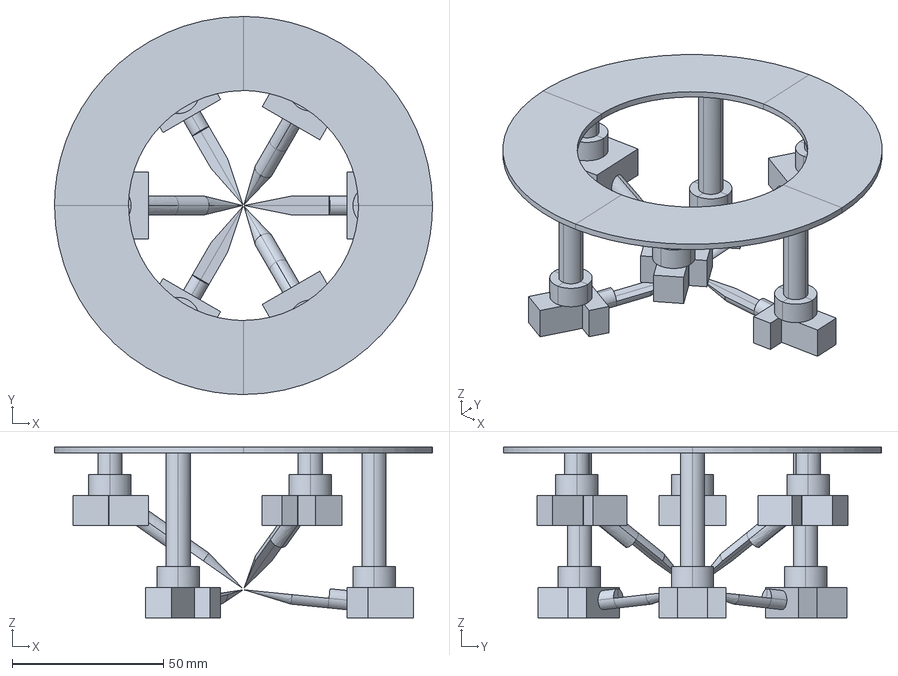
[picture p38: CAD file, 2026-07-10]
magnetic_sim/ANSYS/main/model_check/hung_hexapole/hung_full_assembly_basegap.iges
125.0 x 125.0 x 56.5 mm

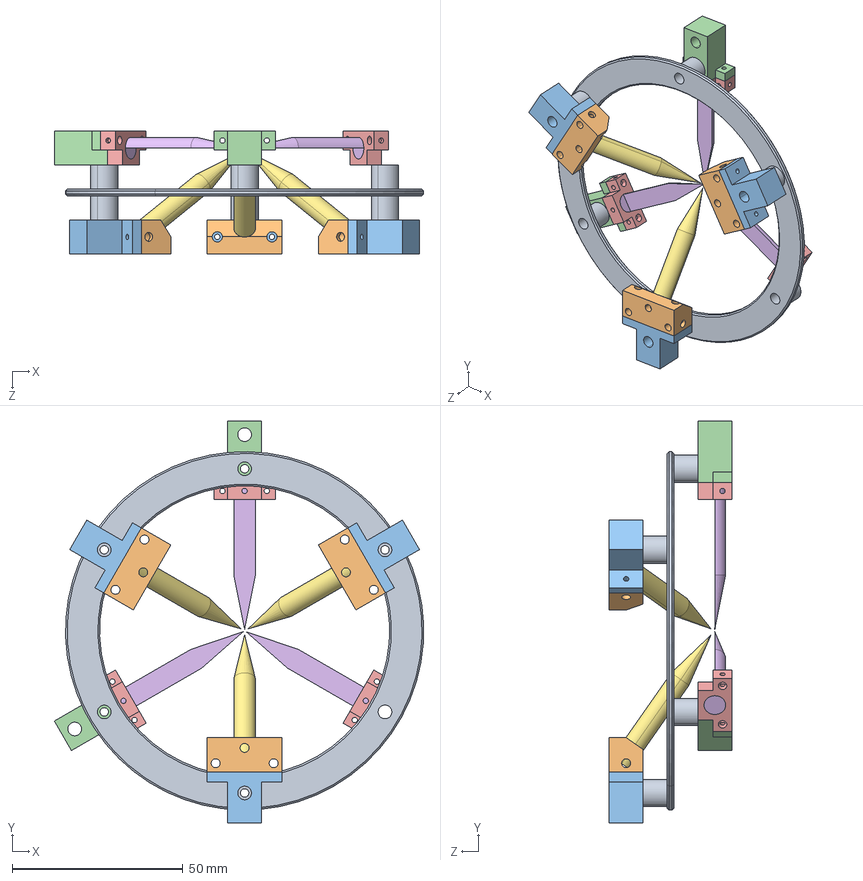
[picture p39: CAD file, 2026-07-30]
magnetic_sim/ANSYS/main/CAD_model/long_fei/STEP/ASSEM_The_Whole_Setup.STEP
108.2 x 117.8 x 36.0 mm
Yoke ring
Pole block front x 3
Pole block top x 3
Pole block Bottom x 2
Pole block bottom front x 3
Magnetic pole Bottom x 3
Magnetic pole x 3

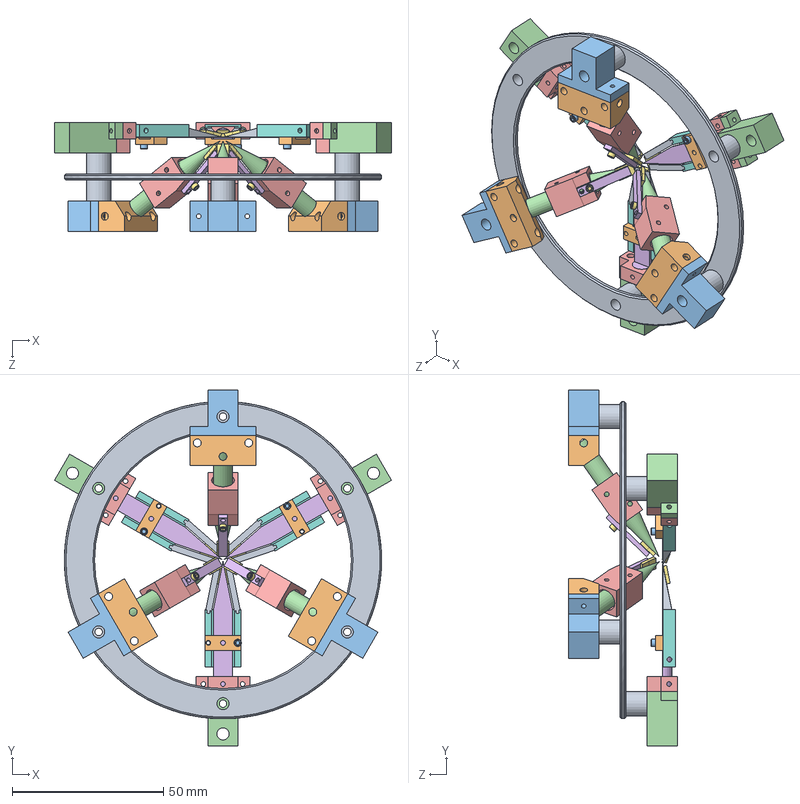
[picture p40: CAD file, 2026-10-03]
magnetic_sim/ANSYS/main/CAD_model/long_fei/SLDPRT/Fan/ASSEM_SixPoles_HallSensors.SLDASM
111.5 x 117.8 x 36.0 mm
Yoke ring
Pole block front x 3
Pole block top x 3
Pole block Bottom x 3
Pole block bottom front x 3
Magnetic pole Bottom x 3
HallSensor_730L (Fei) x 12
HallSensor_Bone_Bottom_Body x 3
HallSensor_Bone_Bottom_Branch x 6
HallSensor_Bone_Bottom_Cover x 3
#0-80_5%32'' x 3
Magnetic pole x 3
HallSensor_Bone_Top_body x 3
HallSensor_Bone_Top_Branch x 3
#0-80_3%32'' x 3

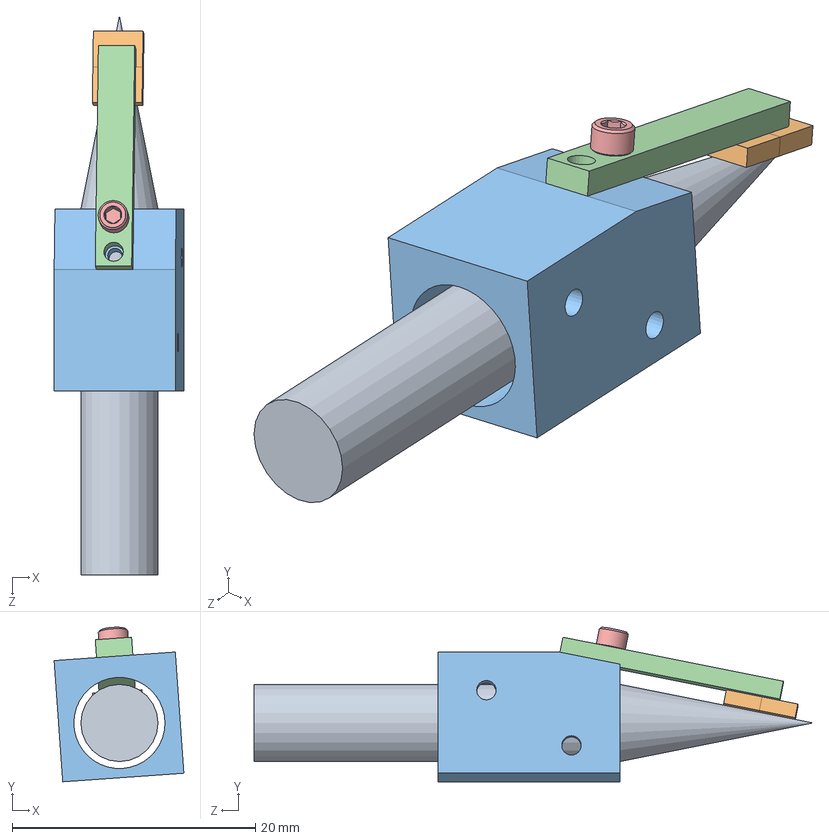
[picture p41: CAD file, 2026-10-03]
magnetic_sim/ANSYS/main/CAD_model/long_fei/SLDPRT/Fan/ASSEM_UpperPole_HallSensor.SLDASM
10.7 x 12.7 x 46.0 mm
Magnetic pole
HallSensor_730L (Fei) x 2
HallSensor_Bone_Top_body
HallSensor_Bone_Top_Branch
#0-80_3%32''

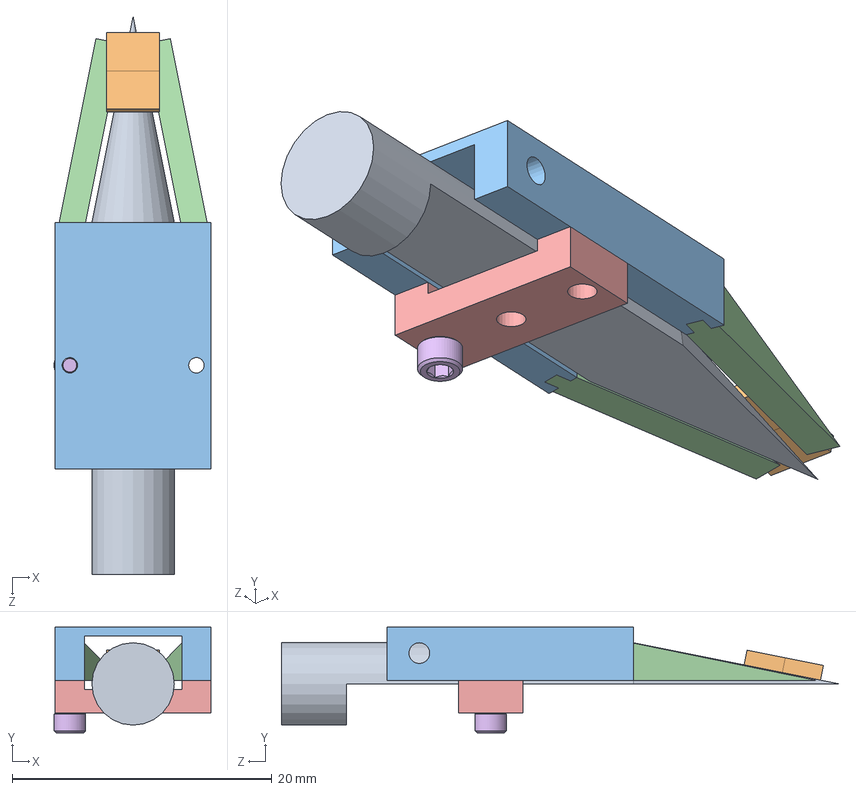
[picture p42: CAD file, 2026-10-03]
magnetic_sim/ANSYS/main/CAD_model/long_fei/SLDPRT/hall sensor assembly and Supporter Structure (2014-10-9)/ASSEM_LowerPole_HallSensor.SLDASM
12.1 x 8.14 x 43.0 mm
Magnetic pole Bottom
HallSensor_730L (Fei) x 2
HallSensor_Bone_Bottom_Body
HallSensor_Bone_Bottom_Branch x 2
HallSensor_Bone_Bottom_Cover
#0-80_5%32''

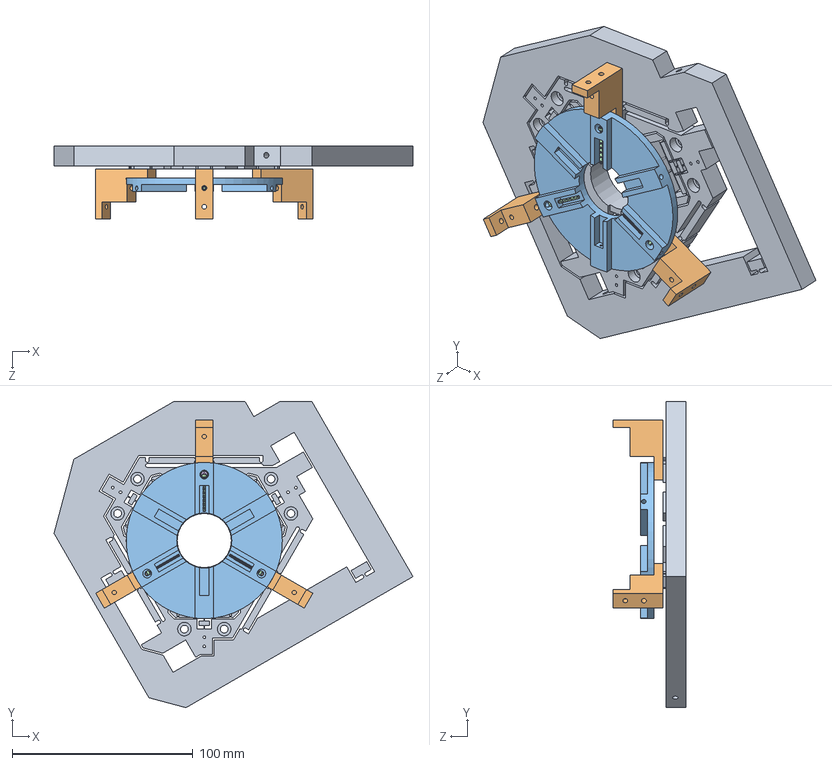
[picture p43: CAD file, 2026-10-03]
magnetic_sim/ANSYS/main/CAD_model/long_fei/SLDPRT/hall sensor assembly and Supporter Structure (2014-10-9)/ASSEM_Base_Plate.SLDASM
198.6 x 169.5 x 40.5 mm
Base_Plate_For_Lower_Poles
Pole_Support_Lower x 3
Vibration_Isolator_Plate
0-80_3o4'' x 3
M2_12mm
M2_4mm

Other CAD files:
magnetic_sim/ANSYS/main/CAD_model/NTU_hexapole/SLDPRT/建棋模擬/pole組合.SLDASM
magnetic_sim/ANSYS/main/model_check/hung_hexapole/hung_full_assembly.iges
magnetic_sim/ANSYS/main/CAD_model/long_fei/SLDPRT/hall sensor assembly and Supporter Structure (2014-10-9)/Illustration_Assembly.IGS
magnetic_sim/ANSYS/main/CAD_model/long_fei/SLDPRT/hall sensor assembly and Supporter Structure (2014-10-9)/ASSEM_UpperPole_HallSensor.SLDASM
magnetic_sim/ANSYS/backup/hung/IGES/Coil.iges
magnetic_sim/ANSYS/backup/hung/IGES/Full_Assembly_Dfillet_l250.iges
magnetic_sim/ANSYS/backup/hung/IGES/Full_Assembly_filleted.iges
magnetic_sim/ANSYS/backup/hung/IGES/Full_Assembly_inch.iges
magnetic_sim/ANSYS/backup/hung/IGES/Full_Assembly_round_filleted.iges
magnetic_sim/ANSYS/backup/hung/IGES/Mag_Guide_Post.iges
magnetic_sim/ANSYS/backup/hung/IGES/Mag_Pole_Bottom.iges
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

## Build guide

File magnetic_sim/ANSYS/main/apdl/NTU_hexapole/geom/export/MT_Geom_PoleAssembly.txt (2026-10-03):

! ============================================================================
! NTU_hexapole — pole ASSEMBLY (磁極 pole.STEP + 短導柱 short guide post)
! ----------------------------------------------------------------------------
! Rebuilt PARAMETRICALLY from CAD. Model frame = 磁極(pole.STEP) local frame.
! ⚠ pole組合.STEP is an ASSEMBLY: each part has its own local frame + transform.
!   Correct positions obtained by baking transforms via OpenCascade (OCP).
!   短導柱 offset in pole frame = T_post(#104) - T_pole(#589) = (+20.5, 0, +11.25).
!
! Parts (all analytic, no NURBS; mm coords):
!  A) 磁極 = flat planar pole, 0.25mm thick, 2D profile extruded +z (unchanged).
!  B) 短導柱 = SOLID stepped cylinder (full; tip recess/flats OMITTED per user),
!       axis (x=20.5, y=0) upright +Z:  r2.5 z 0.25->11.25 ; r2.49 z 11.25->17.25.
!
! Kept as SEPARATE volumes (no boolean); post base sits on the plate top at x~20.5.
!
! Unit toggle UNIT_MM: 1 = mm -> model_check/ (patch flag 6->2) ; 0 = metre -> IGES/.
! Output name = pole_assembly (does NOT overwrite the pole-only pole.iges).
! ============================================================================

! [MODIFIED 2026-08-17] /CWD removed - db/geom/ retired; working dir now comes from launcher -dir

Finish
/cle
/PREP7
*afun, DEG

! ---- [ADDED] unit toggle ---------------------------------------------------
UNIT_MM = 1
*if, UNIT_MM, eq, 1, then
    SC = 1.0
    BTOL, 1e-4
*else
    SC = 1.0e-3
    BTOL, 1e-7
*endif
/UNITS, MKS

! ============================================================================
! PART A — 磁極 (flat pole, 2D profile z=0 -> extrude 0.25 mm)
! ============================================================================
TH = 0.25*SC

K, 1,  0.357*SC,  0.005*SC, 0       ! A tip upper
K, 2,  0.353*SC,  0.000*SC, 0       ! B tip point
K, 3,  0.357*SC, -0.005*SC, 0       ! C tip lower
K, 4,  4.509*SC, -0.523*SC, 0       ! D
K, 5,  6.175*SC, -0.877*SC, 0       ! E
K, 6, 19.048*SC, -4.784*SC, 0       ! F
K, 7, 19.048*SC,  4.784*SC, 0       ! G
K, 8,  6.175*SC,  0.877*SC, 0       ! H
K, 9,  4.509*SC,  0.523*SC, 0       ! I
K, 10, 25.500*SC,  0.000*SC, 0      ! far r5 CONVEX apex (on circle 20.5+5)
K, 101,  0.358*SC,   0.000*SC, 0    ! tip 5um fillet centre
K, 102,  3.271*SC, -10.446*SC, 0    ! lower r10 centre
K, 103,  3.271*SC,  10.446*SC, 0    ! upper r10 centre
K, 104, 20.500*SC,   0.000*SC, 0    ! far r5 centre

LARC, 1, 2, 101, 0.005*SC           ! L1  tip arc upper
LARC, 2, 3, 101, 0.005*SC           ! L2  tip arc lower
L,    3, 4                          ! L3
LARC, 4, 5, 102, 10.0*SC            ! L4  lower r10
L,    5, 6                          ! L5
LARC, 6, 10, 104, 5.0*SC            ! L6  far r5 lower half
LARC, 10, 7, 104, 5.0*SC            ! L7  far r5 upper half
L,    7, 8                          ! L8
LARC, 8, 9, 103, 10.0*SC            ! L9  upper r10
L,    9, 1                          ! L10

AL, 1, 2, 3, 4, 5, 6, 7, 8, 9, 10
VEXT, 1, , , 0, 0, TH               ! -> pole volume
KDELE, 101, 104, 1                  ! drop pole guide keypoints

! ============================================================================
! PART B — 短導柱 = SOLID stepped cylinder (full, no tip recess/flats)
!   Position in pole frame: axis (x=20.5, y=0), upright +Z.
!   = 短導柱.STEP native (Z axis, r2.5 z-11->0, r2.49 z0->6) + assembly
!     offset (+20.5, 0, +11.25)  [from OCC-baked pole組合 transforms:
!     T_post(#104) - T_pole(#589)]. base sits on plate top at x~20.5.
! ============================================================================
POSTX = 20.5*SC                     ! post axis x (pole frame)
WPOFFS, POSTX, 0, 0                 ! move WP origin onto post axis
CYLIND, 2.50*SC, , 0.25*SC, 11.25*SC    ! lower round r2.5   z 0.25 -> 11.25
CYLIND, 2.49*SC, , 11.25*SC, 17.25*SC   ! upper round r2.49  z 11.25 -> 17.25 (tip, solid)
WPOFFS, -POSTX, 0, 0                ! restore WP to origin

! ---- finalise + IGES -------------------------------------------------------
ALLSEL, ALL
NUMCMP, ALL

*if, UNIT_MM, eq, 1, then
    IGESOUT, 'G:\my_workspace\FEM_sim\magnetic_sim\ANSYS\main\model_check\NTU_hexapole\pole_assembly', 'iges'
! [MODIFIED 2026-08-17] metre-unit IGESOUT removed - only mm IGES is needed
*endif

SAVE

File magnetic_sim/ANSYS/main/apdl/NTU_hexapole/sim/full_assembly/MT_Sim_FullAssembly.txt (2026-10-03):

! ============================================================================
! MT_Sim_FullAssembly.txt — NTU_hexapole full_assembly_sleeve solve deck（RESUME db/mesh/full_assembly_sleeve）
!   [MODIFIED] 含 6 襯套（μr=280 鐵件，併入 return body）的變體 full_assembly_sleeve；線圈參數不變。
!   mesh/solve 分離：RESUME mesh/MT_Mesh_Graded_Full.txt 產的 full_assembly_sleeve.db（含幾何+網格+材料+三層空氣），
!   加 6 SOURC36 線圈（只 CN 那顆激發）+ D,ALL,MAG,0 遠場 BC，magsolv,3 求解，抽 B 場 → data/full_assembly_sleeve/coilCN/。
!   公尺 MKS。**6 顆各別 solve**：CN 選 active coil（driver sed temp copy 的 CN 行到 '2'..'6'；coil1=預設）。
!   線圈：內半徑3.5/外半徑7.5/徑厚4.0/高4.2mm、與導柱同軸、z 中心18.7(z[16.6,20.8])、1A×50匝反向。
!   APDL coil 1-6 → 方位 0/120/240/60/180/300° → 紙名 P1/P3/P6/P5/P2/P4（同 long_fei）。
! ============================================================================
/CWD,'G:\my_workspace\FEM_sim\magnetic_sim\ANSYS\main\ANSYS_data\NTU_hexapole\db\sim\full_assembly_sleeve'
Finish

! ----- RESUME mesh-only 模型（幾何+網格+材料+空氣；含 params SC 等）-----
RESUME,'full_assembly_sleeve','db','G:\my_workspace\FEM_sim\magnetic_sim\ANSYS\main\ANSYS_data\NTU_hexapole\db\mesh\full_assembly_sleeve\'

/PREP7
*afun, DEG

! ----- active coil 選擇（driver 對 temp copy sed 這兩行到 N / 'N'；coil1=預設）-----
!   ⚠ 必須放 RESUME 之後（RESUME 會清掉 RESUME 前設的 params）
COIL_ID = 1                       ! active coil 數字 index（CURR_ARRAY 用）
CN = '1'                          ! 線圈 tag 字串（data 夾名 coil%CN%）

! ----- RESUME-safe 常數（BC / coil / extract）-----
SC = 1.0e-3
WPZ = 9.3*SC                     ! WP z（空氣中心；mesh 建於此）
AIR_CYL_R = 100.0*SC
AIR_CYL_H = 110.0*SC
AIR_CYL_Z_TOP = WPZ + AIR_CYL_H/2    ! +64.3mm 端蓋
AIR_CYL_Z_BOT = WPZ - AIR_CYL_H/2    ! -45.7mm 端蓋
RPOST     = 20.5*SC              ! 線圈/導柱徑向
COIL_IN_R = 3.5*SC
COIL_OUT_R= 7.5*SC
COIL_R    = (COIL_IN_R + COIL_OUT_R)/2   ! 5.5mm 平均半徑
COIL_THK  = COIL_OUT_R - COIL_IN_R       ! 4.0mm 徑向厚 (SOURC36 DY)
COIL_H    = 4.2*SC                        ! 4.2mm 軸向高 (SOURC36 DZ)
COILZ     = 18.7*SC                        ! 線圈中心 z（z[16.6,20.8]）
TURNS     = 50
CURR      = 1

! ----- 6 線圈方位（APDL index → 方位角）-----
*dim, PANG, , 6
PANG(1)=0 $ PANG(2)=120 $ PANG(3)=240 $ PANG(4)=60 $ PANG(5)=180 $ PANG(6)=300
! ----- CURR_ARRAY：只 active(COIL_ID) 那顆 = 1，其餘 0 -----
*dim, CURR_ARRAY, , 6
*do, k, 1, 6
    CURR_ARRAY(k) = 0
*enddo
CURR_ARRAY(COIL_ID) = 1

! ----- 6 SOURC36 線圈（mesh 未含 coil，於此加）-----
ET_curr = 2
ET, ET_curr, SOURC36
*get, NODE_NUM, NODE, , NUM, MAX
*do, N, 1, 6
    CX = RPOST*cos(PANG(N))
    CY = RPOST*sin(PANG(N))
    ! [MODIFIED] 電流反向（磁路往磁極跑）→ R2 = -TURNS*CURR_ARRAY(N)（非 active 顆=0）
    R, N, 1, -TURNS*CURR_ARRAY(N), COIL_THK, COIL_H
    n1 = NODE_NUM + 3*(N-1) + 1
    n2 = NODE_NUM + 3*(N-1) + 2
    n3 = NODE_NUM + 3*(N-1) + 3
    N, n1, CX + COIL_R, CY,          COILZ    ! 線圈 +x
    N, n2, CX,          CY + COIL_R, COILZ    ! 線圈 +y
    N, n3, CX,          CY,          COILZ    ! 中心
    TYPE, ET_curr
    REAL, N
    E, n1, n2, n3
*enddo

! ----- 遠場 BC: MAG=0 於外圓柱側面(r≈100) + 上下端蓋(z≈WP±55) -----
LOCAL,11,1,0,0,0                 ! 圓柱 CS @ 原點（軸=z，通過 WP xy=0）
CSYS,11
NSEL,S,LOC,X, AIR_CYL_R - 0.5e-3, AIR_CYL_R + 0.5e-3
CSYS,0
NSEL,A,LOC,Z, AIR_CYL_Z_TOP - 0.5e-3, AIR_CYL_Z_TOP + 0.5e-3
NSEL,A,LOC,Z, AIR_CYL_Z_BOT - 0.5e-3, AIR_CYL_Z_BOT + 0.5e-3
D,ALL,MAG,0
ALLSEL,ALL
FINISH

! ----- solve -----
/SOLU
magsolv,3,,,,,1                  ! DSP;若 OOM 改 EQSLV,PCG（見 sim/README fallback）
FINISH

! ====================================================================
! POST1: 抽 B 場全節點 → data/full_assembly/coil%CN%/
! ====================================================================
/POST1
SET,LAST
ALLSEL,ALL
/HEADER,OFF,OFF,OFF,OFF,OFF,OFF
/FORMAT,10,,20,12,,
/PAGE,1000000,,1000000

/OUTPUT,'G:\my_workspace\FEM_sim\magnetic_sim\ANSYS\main\ANSYS_data\NTU_hexapole\data\full_assembly_sleeve\coil%CN%\full_assembly_sleeve_coord_all','dat'
NLIST,ALL, , ,COORD
/OUTPUT
/OUTPUT,'G:\my_workspace\FEM_sim\magnetic_sim\ANSYS\main\ANSYS_data\NTU_hexapole\data\full_assembly_sleeve\coil%CN%\full_assembly_sleeve_bfield_all','dat'
PRNSOL,B,COMP
/OUTPUT

ALLSEL,ALL
SAVE,'sim_coil%CN%','db'                          ! [MODIFIED] 交付 db/sim/full_assembly_sleeve/sim_coilN.db
FINISH

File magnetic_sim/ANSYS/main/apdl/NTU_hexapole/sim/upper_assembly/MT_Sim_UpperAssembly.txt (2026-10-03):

! ============================================================================
! MT_Sim_UpperAssembly.txt — NTU_hexapole 上層完整組合 solve deck（RESUME mesh_graded_upper.db）
!   mesh/solve 分離：RESUME ../../mesh/MT_Mesh_Graded_Upper.txt 產的 mesh_graded_upper.db，
!   加 SOURC36 線圈（1A×50匝，反向，與 post0 同軸）+ D,ALL,MAG,0 遠場 BC，
!   magsolv,3(DSP) 求解，抽 B 場 .dat（全節點 + 2 顆 sensor 加密球）到 data/upper_assembly/coil1/。
!   MKS metre。**沿用單極單組激發**：只 post0(0°) 一顆線圈 + pole0 兩顆 sensor（同單極設定）。
!   量 yoke + 鄰極對 pole0 sensor 的磁路耦合影響。比照 sim/singlepole/MT_Sim_SinglePole.txt。
! ============================================================================
/CWD,'G:\my_workspace\FEM_sim\magnetic_sim\ANSYS\main\ANSYS_data\NTU_hexapole\db\sim\upper_assembly'
Finish
/cle
/CLEAR,NOSTART
/TITLE, NTU_hexapole upper assembly - solve 1A x 50 turns post0 (RESUME mesh_graded_upper.db)
/FILNAME,sim_upper_assembly,1

! ----- restore mesh-only model (geometry + mesh + materials + sensor spheres) -----
RESUME,'mesh_graded_upper','db','G:\my_workspace\FEM_sim\magnetic_sim\ANSYS\main\ANSYS_data\NTU_hexapole\db\mesh\mesh_graded_upper\'

/PREP7
*afun, DEG

! ----- RESUME-safe 常數（BC / coil / extract 需要）-----
SC = 1.0e-3
! 外圓柱遠場（mesh 建於 z[-55,55]、中心 z=0；enlarged 自單極以含 yoke）
AIR_CYL_R = 100.0*SC
AIR_CYL_H = 110.0*SC
AIR_CYL_Z_TOP =  AIR_CYL_H/2          !  +55mm 端蓋
AIR_CYL_Z_BOT = -AIR_CYL_H/2          !  -55mm 端蓋
! 線圈（與 post0 同軸；沿用單極交付：內半徑R3.5 外半徑R7.5 高4.2 z7.05-11.25）
POSTX     = 20.5*SC                   ! post0 軸 x
COIL_IN_R = 3.5*SC
COIL_OUT_R= 7.5*SC
COIL_R    = (COIL_IN_R + COIL_OUT_R)/2   ! 5.5mm 平均半徑
COIL_THK  = COIL_OUT_R - COIL_IN_R       ! 4.0mm 徑向厚 (SOURC36 DY)
COIL_H    = 4.2*SC                        ! 4.2mm 軸向高 (SOURC36 DZ)
COILZ     = (7.05*SC + 11.25*SC)/2        ! 9.15mm node 平面（線圈 ±COIL_H/2 → z7.05-11.25）
TURNS     = 50
CURR      = 1
! sensor 加密球中心（pole0 frame, metre）— extract 用
S1X = 13.15*SC $ S1Y = -0.99*SC $ S1Z = -0.41*SC     ! n+ -> -z
S2X = 13.15*SC $ S2Y = -0.99*SC $ S2Z =  0.66*SC     ! n+ -> +z
SENS_R = 0.15*SC
MAT_SENS = 5

! ----- SOURC36 線圈（mesh_graded_upper.db 未含 coil，於此加）-----
ET_curr = 2
ET, ET_curr, SOURC36
! [MODIFIED] 電流反向（磁路要往磁極跑）→ CUR 取負，翻轉線圈激發磁通方向（同單極）
R, 1, 1, -TURNS*CURR, COIL_THK, COIL_H    ! R1=1(coil type) R2=-CUR(反向 50 A-turns) R3=DY R4=DZ
*get, NODE_NUM, NODE, , NUM, MAX
n1 = NODE_NUM + 1
n2 = NODE_NUM + 2
n3 = NODE_NUM + 3
N, n1, POSTX + COIL_R, 0,          COILZ    ! 線圈上 +x
N, n2, POSTX,          COIL_R,     COILZ    ! 線圈上 +y
N, n3, POSTX,          0,          COILZ    ! 中心
TYPE, ET_curr
REAL, 1
E, n1, n2, n3

! ----- 遠場 BC: MAG=0 於外圓柱側面(r≈100) + 上下端蓋(z≈±55) -----
LOCAL,11,1,0,0,0                          ! 圓柱 CS @ origin
CSYS,11
NSEL,S,LOC,X, AIR_CYL_R - 0.5e-3, AIR_CYL_R + 0.5e-3
CSYS,0
NSEL,A,LOC,Z, AIR_CYL_Z_TOP - 0.5e-3, AIR_CYL_Z_TOP + 0.5e-3
NSEL,A,LOC,Z, AIR_CYL_Z_BOT - 0.5e-3, AIR_CYL_Z_BOT + 0.5e-3
D,ALL,MAG,0
ALLSEL,ALL
FINISH

! ----- solve -----
/SOLU
magsolv,3,,,,,1
FINISH

! ====================================================================
! POST1: 抽 B 場 .dat → data/upper_assembly/coil1/（scratch 留 db/sim/upper_assembly/）
! ====================================================================
/POST1
SET,LAST
ALLSEL,ALL
/HEADER,OFF,OFF,OFF,OFF,OFF,OFF
/FORMAT,10,,20,12,,
/PAGE,1000000,,1000000

! ---- 全節點 ----
/OUTPUT,'G:\my_workspace\FEM_sim\magnetic_sim\ANSYS\main\ANSYS_data\NTU_hexapole\data\upper_assembly\coil1\upper_assembly_coord_all','dat'
NLIST,ALL, , ,COORD
/OUTPUT
/OUTPUT,'G:\my_workspace\FEM_sim\magnetic_sim\ANSYS\main\ANSYS_data\NTU_hexapole\data\upper_assembly\coil1\upper_assembly_bfield_all','dat'
PRNSOL,B,COMP
/OUTPUT

! ---- S1 sensor 加密球（MAT_SENS 節點 ∩ S1 z 帶）----
ESEL,S,MAT,,MAT_SENS
NSLE,S
NSEL,R,LOC,Z, S1Z-SENS_R, S1Z+SENS_R
/OUTPUT,'G:\my_workspace\FEM_sim\magnetic_sim\ANSYS\main\ANSYS_data\NTU_hexapole\data\upper_assembly\coil1\upper_assembly_coord_sensor_S1','dat'
NLIST,ALL, , ,COORD
/OUTPUT
/OUTPUT,'G:\my_workspace\FEM_sim\magnetic_sim\ANSYS\main\ANSYS_data\NTU_hexapole\data\upper_assembly\coil1\upper_assembly_bfield_sensor_S1','dat'
PRNSOL,B,COMP
/OUTPUT
ALLSEL,ALL

! ---- S2 sensor 加密球 ----
ESEL,S,MAT,,MAT_SENS
NSLE,S
NSEL,R,LOC,Z, S2Z-SENS_R, S2Z+SENS_R
/OUTPUT,'G:\my_workspace\FEM_sim\magnetic_sim\ANSYS\main\ANSYS_data\NTU_hexapole\data\upper_assembly\coil1\upper_assembly_coord_sensor_S2','dat'
NLIST,ALL, , ,COORD
/OUTPUT
/OUTPUT,'G:\my_workspace\FEM_sim\magnetic_sim\ANSYS\main\ANSYS_data\NTU_hexapole\data\upper_assembly\coil1\upper_assembly_bfield_sensor_S2','dat'
PRNSOL,B,COMP
/OUTPUT

ALLSEL,ALL
SAVE
FINISH

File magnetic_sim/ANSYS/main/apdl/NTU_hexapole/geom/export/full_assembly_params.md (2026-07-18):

# NTU_hexapole `full_assembly` — 組裝框參數（從 總組合.STEP OCC 量測）

**來源**：`CAD_model/NTU_hexapole/STEP/總組合.STEP`（OCP 世界座標量測；`make_full_assembly_step.py` 擺件之 bbox 與 CAD 原始 solid 逐一吻合 ±0.05mm）。
**階段**：整體 model 的**階段性建構**。**階段① = 6 磁極**（solid0–5）；**階段② = 6 導柱**（solid07–12）；**階段③ = yoke**（solid06）。命名 `full_assembly`（之後同 deck 擴充 coil）。
**總組合.STEP 全貌**：19 solids = 6 磁極 + 1 yoke(solid06) + **6 導柱(solid07–12)** + 6 襯套(solid13–18)。deck 已建 6 磁極 + 6 導柱 + 1 yoke + **6 襯套** = **19 volumes**（襯套 2026-07-17 加）。

**襯套（sleeve/bushing，solid13–18）**：凸緣頂帽狀空心襯套，軸向 +z。用**總組合.STEP 尺寸**（⚠ 單件 襯套.STEP 舊版小 0.5mm：tube r3.0/flange r7.0）：
- bore（內孔）**r2.5**（貫穿；套上 r2.5 導柱）、tube 外徑 **r3.5**、flange 外徑 **r7.5**。
- flange 段 z[15.60, 16.60]（厚 1.0、r7.5）；tube 段 z[16.60, 20.80]（長 4.2、r3.5）；bore r2.5 貫穿 z[15.60, 20.80]。
- 6 個在 r=20.5 @ 0/60/120/180/240/300°、全垂直、同 z（tube 頂 20.80 接 yoke 底）、與 6 導柱同軸。
**座標系**：**對齊 總組合.STEP 原點（不平移）**——磁極在 z≈9mm，不移到 z=0。單位：FEM 公尺 MKS（`SC=1e-3`）/ model_check mm（`SC=1.0`）。
**磁極輪廓**：見 `pole_params.md`（扁平 0.25mm 板、9 段封閉環、局部尖端 (0.358,0)、遠端凸弧 r5 頂點 (25.5,0)）。

## 6 磁極 = 兩平行薄板層（各厚 0.25mm）
| 層 | z 範圍 (mm) | 板底 z_b (mm) | 3 極方位（凸端 = WPROTA 角）| 凸端 dir |
|---|---|---|---|---|
| **下層** | [8.80, 9.05] | **8.80** | **0° / 120° / 240°** | −z |
| **上層** | [9.55, 9.80] | **9.55** | **60° / 180° / 300°** | +z |

- 凸端(遠端)半徑 **20.5**、尖端半徑 **0.358**、凸弧頂 25.5；**WP(中心) = xy 原點 (0,0)**。
- 層間隙 0.5mm（9.05→9.55）；板底距 **ΔZ = 0.75mm**。
- 磁極 local **+x = 凸端方向**（body 朝方位角、尖端朝中心 WP）→ 每極 `WPROTA` 該方位角。
- 建法：重用 `MT_Geom_UpperAssembly.txt` PART A 的 K/L/LARC/AL/VEXT（輪廓不變），跑**兩層 × 3 極**、WP 平面設在該層 z_b。

## OCC 量測對照（世界座標 bbox，mm）
| 磁極 | 層/方位 | X | Y | Z |
|---|---|---|---|---|
| P(下0°)  | 下/0° | [0.35,25.50]  | [−5.00,5.00] | [8.80,9.05] |
| P(下120°)| 下/120° | [−15.25,−0.17]| [0.31,22.75] | [8.80,9.05] |
| P(下240°)| 下/240° | [−15.25,−0.17]| [−22.75,−0.31] | [8.80,9.05] |
| P(上60°) | 上/60°  | [0.17,15.25]  | [0.31,22.75] | [9.55,9.80] |
| P(上180°)| 上/180° | [−25.50,−0.35]| [−5.00,5.00] | [9.55,9.80] |
| P(上300°)| 上/300° | [0.17,15.25]  | [−22.75,−0.31] | [9.55,9.80] |

---

## 6 導柱（階段②；guide posts）
從 總組合.STEP OCC 量測（solid07–12）：6 根皆 **半徑 2.5、徑向位置 r=20.5（沿各磁極方位軸）、頂端齊平 z=26.80**，底端坐各自磁極板頂面。
**尖端簡化**：CAD 導柱有 r2.5 本體 + r2.49 尖段（差 0.01mm）→ 使用者拍板**建成整根 r2.5 實心圓柱**（deck `CYLIND`、model_check OCC primitive 皆 r2.5）。

| 導柱 | 方位角 | 對應磁極層 | 底 z（磁極頂面）| 頂 z | 長度 | CAD 檔 |
|---|---|---|---|---|---|---|
| 長導柱 ×3 | 0 / 120 / 240° | 下層（頂面 9.05） | **9.05** | 26.80 | **17.75** | `導柱.step` |
| 短導柱 ×3 | 60 / 180 / 300° | 上層（頂面 9.80） | **9.80** | 26.80 | **17.00** | `短導柱.step` |

- 導柱中心 (x,y) = (20.5·cosθ, 20.5·sinθ)；長度差 0.75 = 上下磁極板頂面高差（9.80−9.05），6 根共用頂端 26.80。
- deck：兩層 WPROTA loop（`WPROTA,ANG` + `WPOFFS,RPOST,0,0` + `CYLIND,RP,,ZBP,ZTOP`），每根一 volume、**不 boolean**（保留位置目視檢查）。

### OCC 導柱 bbox 對照（世界座標，mm；CAD solid07–12 vs 本 deck/STEP 產出，逐一吻合）
| 導柱 | 層/方位 | X | Y | Z |
|---|---|---|---|---|
| 導柱(0°)  | 下/0° | [18.00,23.00]  | [−2.50,2.50] | [9.05,26.80] |
| 導柱(120°)| 下/120° | [−12.75,−7.75] | [15.25,20.25]  | [9.05,26.80] |
| 導柱(240°)| 下/240° | [−12.75,−7.75] | [−20.25,−15.25]| [9.05,26.80] |
| 短導柱(60°) | 上/60°  | [7.75,12.75] | [15.25,20.25]  | [9.80,26.80] |
| 短導柱(180°)| 上/180° | [−23.00,−18.00]| [−2.50,2.50] | [9.80,26.80] |
| 短導柱(300°)| 上/300° | [7.75,12.75] | [−20.25,−15.25]| [9.80,26.80] |

---

## yoke（階段③；磁軛盤 = solid06）
從 總組合.STEP OCC 量測（solid06）：**rounded-rect 外盤 − rounded-rect 中心 cutout − 6 孔**，厚 5.5 @ **z[20.80,26.30]**。
**忠實 r5 圓角**（使用者拍板；外盤 4 角 + cutout 4 角都建 r5，不省略）。model_check STEP **直接嵌 CAD 真 yoke（solid06）**。

| 元素 | 尺寸（mm） | r5 圓角中心 |
|---|---|---|
| 外盤 | X ±29.9、Y ±26.9（59.8×53.8） | (±24.9, ±21.9) |
| 中心 cutout | X ±15.5、Y ±10.25（31×20.5） | (±10.5, ±5.25) |
| 6 孔 r2.5 | (±20.5,0)/(±10.25,±17.75) | — |

- **6 孔位 = 6 導柱位置完全吻合**（導柱穿 yoke 孔；孔 r2.5 = 導柱 r2.5，共面相接）。厚 5.5、底 20.80、頂 26.30。
- deck：rounded-rect 面（8 邊界 KP + 4 圓角中心 KP → 4 直邊 L + 4 角弧 LARC r5 → AL → VEXT 5.5）；外盤 + cutout `*do,ir,1,2` 參數化；6 孔 CYLIND；一次 `VSBV,V_OUT,ALL`（外盤 − cutout − 6 孔）→ **yoke 1 volume**。
- OCC bbox 驗：solid12(產出) = X[−29.90,29.90] Y[−26.90,26.90] Z[20.80,26.30]，與 CAD solid06 完全一致。

相關：`pole_params.md`（磁極輪廓 + 短導柱原始尺寸）、`MT_Geom_UpperAssembly.txt`（PART C yoke sharp 版）、`make_full_assembly_step.py`、`model_check/NTU_hexapole/full_assembly.step`。

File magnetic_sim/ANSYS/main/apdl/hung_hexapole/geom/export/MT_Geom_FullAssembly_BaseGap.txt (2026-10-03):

! =======================================
! MT_Hung_SphereModel.txt
! [ADDED] 從球面幾何建立 6 根 D 型 pole
! 上層 (P2, P4, P5)：相對水平往上傾斜 35°
! 下層 (P1, P3, P6)：相對水平往下傾斜 5.71°
! R_sphere = 0.5mm, 方位角 120° 等距, magic angle
! Pole 尺寸來自 Mag_Pole_Bottom.STEP
! =======================================

! [MODIFIED 2026-08-17] /CWD removed - db/geom/ retired; working dir now comes from launcher -dir

/PREP7
*afun, DEG
BTOL, 1e-5
! [MODIFIED] SolidWorks 讀 IGES 固定當英寸 → 內部用英寸建模
! SolidWorks 匯入後自動 ×25.4 → 顯示為正確 mm 值
MM = 1.0/25.4                 ! [ADDED] 1mm = 0.03937 inches
! [MODIFIED 2026-07-09 EXPERIMENT] 下極 gap slab radial：40=移進 Part1 series 鋼(導柱 43.2 內側、過縮短鐵棒 ~38.5)翻反增益；原 45/48 在 Part2 漏磁。上極不動 44.43
GLOW_R = 40.0
! [ADDED 2026-07-09 EXPERIMENT] 下極鐵棒長(只縮下極,末端~38.5<gap 40,block/導柱/coil 仍用 43)；必須 *MM 與 POLE_TOTAL_LEN 同單位(用作 fc_ex=p1+fc_rodlen*unitdir)。非 CAD baseline
ROD_LEN_LO = 38.0*MM
! [ADDED 2026-07-09 EXPERIMENT] 下極氣隙切刀 tangential 半寬 [mm]；5=10mm寬，配下極 block 高 10mm → 氣隙截面~100mm²(中央,兩側各留6mm鋼橋,不改鐵/partial cut)。上極切刀不動(±12)
GAP_HW_LO = 5.0

! ===== Pole 尺寸 (from Mag_Pole_Bottom.STEP) =====
POLE_R         = 3.175*MM     ! [MODIFIED] 圓柱半徑
POLE_CONE_LEN  = 15.875*MM    ! [MODIFIED] 錐段長度
POLE_TOTAL_LEN = 43.0*MM      ! [MODIFIED] 總長
POLE_FLAT_LEN  = 28.0*MM      ! [MODIFIED] 削平長度

! [MODIFIED] Tip fillet 80 µm diameter = 40 µm radius (與 sim 腳本 + Long 2016 一致)
POLE_TIP_R    = 0.040*MM
PCH           = sqrt(POLE_CONE_LEN*POLE_CONE_LEN + POLE_R*POLE_R)
FANG1         = acos(POLE_R/PCH)
FANG2         = 90 - FANG1
LFIL          = POLE_CONE_LEN*POLE_TIP_R/POLE_R
PTC           = LFIL/cos(FANG2)
PCN2          = LFIL*cos(FANG2)
PTR2          = POLE_TIP_R*cos(FANG2)
FDROP         = PTC - POLE_TIP_R
FPROT         = PCN2 - FDROP
JUNC_X        = POLE_CONE_LEN - FDROP    ! cone-cyl 接點 X (was POLE_CONE_LEN)

! ===== 球面幾何 =====
R_sphere = 0.5*MM             ! [MODIFIED] 球半徑
fc_theta = 54.74              ! [ADDED] magic angle (極角)
fc_h = cos(fc_theta)*R_sphere      ! [MODIFIED] 上層平面高度 (乘號前後不能有空格!)
fc_r = sin(fc_theta)*R_sphere      ! [MODIFIED] 上層圓半徑

TILT_UP = 35.0                ! [ADDED] 上層傾斜角 (度)
TILT_DN = 5.71                ! [ADDED] 下層傾斜角 (度)

! ===== 6 根 pole 定義 =====
! [MODIFIED] ANSYS 座標對齊 measured 座標系：ANSYS +X = X_m = P1 方向
! 索引 1-6 = P1-P6
! 逆時針：P1(0°) P5(60°) P3(120°) P2(180°) P6(240°) P4(300°)
*dim, fc_tx, , 6
*dim, fc_ty, , 6
*dim, fc_tz, , 6
*dim, fc_ia, , 6              ! incline (正=上, 負=下)
*dim, fc_ra, , 6              ! azimuth (outward 方向, = measured 方位角)

! --- P1 (lower, 0°) ---
fc_tx(1) = fc_r
fc_ty(1) = 0
fc_tz(1) = -fc_h
fc_ia(1) = -TILT_DN
fc_ra(1) = 0

! --- P5 (upper, 60°) ---
fc_tx(5) = cos(60)*fc_r
fc_ty(5) = sin(60)*fc_r
fc_tz(5) = fc_h
fc_ia(5) = TILT_UP
fc_ra(5) = 60

! --- P3 (lower, 120°) ---
fc_tx(3) = cos(120)*fc_r
fc_ty(3) = sin(120)*fc_r
fc_tz(3) = -fc_h
fc_ia(3) = -TILT_DN
fc_ra(3) = 120

! --- P2 (upper, 180°) ---
fc_tx(2) = cos(180)*fc_r
fc_ty(2) = sin(180)*fc_r
fc_tz(2) = fc_h
fc_ia(2) = TILT_UP
fc_ra(2) = 180

! --- P6 (lower, 240°) ---
fc_tx(6) = cos(240)*fc_r
fc_ty(6) = sin(240)*fc_r
fc_tz(6) = -fc_h
fc_ia(6) = -TILT_DN
fc_ra(6) = 240

! --- P4 (upper, 300°) ---
fc_tx(4) = cos(300)*fc_r
fc_ty(4) = sin(300)*fc_r
fc_tz(4) = fc_h
fc_ia(4) = TILT_UP
fc_ra(4) = 300

! ===== 建立 6 根 pole（兩段式：前段 D 型 + 後段全圓）=====
*do, fc_pi, 1, 6, 1

    fc_incl = fc_ia(fc_pi)
    fc_azim = fc_ra(fc_pi)

    ! [ADDED 2026-07-09 EXPERIMENT] 每極鐵棒長：下極縮短(ROD_LEN_LO)使 gap(40) 前結束、不橋接；上極維持 POLE_TOTAL_LEN
    fc_rodlen = POLE_TOTAL_LEN
    *if, fc_incl, LT, 0, THEN
        fc_rodlen = ROD_LEN_LO
    *endif

    ! --- 方向向量 ---
    fc_ax = cos(fc_incl)*cos(fc_azim)
    fc_ay = cos(fc_incl)*sin(fc_azim)
    fc_az = sin(fc_incl)

    ! [MODIFIED] 截面偏移方向：決定削平面朝向
    ! Upper pole: -side_perp → VROTAT 180° 保留下半 → 削平面朝上
    ! Lower pole: +side_perp → VROTAT 180° 保留上半 → 削平面朝下（轉 180°）
    *if, fc_incl, GE, 0, THEN
        fc_nsx = -sin(fc_azim)
        fc_nsy = cos(fc_azim)
    *else
        fc_nsx = sin(fc_azim)
        fc_nsy = -cos(fc_azim)
    *endif

    ! --- Numbering ---
    *get, KP_NUM, KP, , NUM, MAX
    *if, KP_NUM, LT, 1, THEN
        KP_NUM = 0
    *endif
    KP_START = KP_NUM + 1
    NUMSTR, KP, KP_START

    *get, LI_NUM, LINE, , NUM, MAX
    *if, LI_NUM, LT, 1, THEN
        LI_NUM = 0
    *endif
    LI_START = LI_NUM + 1
    NUMSTR, LINE, LI_START

    ! --- Tip 位置 ---
    p1x = fc_tx(fc_pi)
    p1y = fc_ty(fc_pi)
    p1z = fc_tz(fc_pi)

    ! --- 軸上關鍵位置 ---
    ! 削平交界（tip 起 28mm）
    fc_fx = p1x + POLE_FLAT_LEN*fc_ax
    fc_fy = p1y + POLE_FLAT_LEN*fc_ay
    fc_fz = p1z + POLE_FLAT_LEN*fc_az
    ! 後端（tip 起 fc_rodlen；下極 38mm / 上極 43mm）[MODIFIED 2026-07-09 EXPERIMENT]
    fc_ex = p1x + fc_rodlen*fc_ax
    fc_ey = p1y + fc_rodlen*fc_ay
    fc_ez = p1z + fc_rodlen*fc_az

    ! ==========================================
    ! [MODIFIED] 前段：tip → 28mm（D 型，VROTAT 180°）+ 40µm fillet
    ! ==========================================
    ! KP+0: foremost (= 原 tip 位置, fillet 最前端)
    ! KP+1: 切線點 (cone 與 fillet 相切點，偏移 -side_perp)
    ! KP+2: 錐-柱交界 (用 JUNC_X，偏移 -side_perp)
    ! KP+3: 削平交界（偏移 -side_perp）
    ! KP+4: 削平交界（軸上）
    ! KP+5: 後端（軸上，僅作 VROTAT 軸用）
    ! KP+6: fillet 球心 (沿 +pole_axis 距 foremost = POLE_TIP_R)

    K, KP_START,   p1x, p1y, p1z
    K, KP_START+1, p1x + FPROT*fc_ax + PTR2*fc_nsx, p1y + FPROT*fc_ay + PTR2*fc_nsy, p1z + FPROT*fc_az
    K, KP_START+2, p1x + JUNC_X*fc_ax + POLE_R*fc_nsx, p1y + JUNC_X*fc_ay + POLE_R*fc_nsy, p1z + JUNC_X*fc_az
    K, KP_START+3, fc_fx + POLE_R*fc_nsx, fc_fy + POLE_R*fc_nsy, fc_fz
    K, KP_START+4, fc_fx, fc_fy, fc_fz
    K, KP_START+5, fc_ex, fc_ey, fc_ez
    K, KP_START+6, p1x + POLE_TIP_R*fc_ax, p1y + POLE_TIP_R*fc_ay, p1z + POLE_TIP_R*fc_az

    LARC, KP_START, KP_START+1, KP_START+6, POLE_TIP_R
    L, KP_START+1, KP_START+2
    L, KP_START+2, KP_START+3
    L, KP_START+3, KP_START+4
    L, KP_START+4, KP_START

    *get, AR_NUM, AREA, , NUM, MAX
    *if, AR_NUM, LT, 1, THEN
        AR_NUM = 0
    *endif
    AR_START = AR_NUM + 1
    NUMSTR, AREA, AR_START
    AL, LI_START, LI_START+1, LI_START+2, LI_START+3, LI_START+4

    VROTAT, AR_START, ,,,, , KP_START, KP_START+5, 180, 2

    ALLSEL, ALL

    ! ==========================================
    ! [ADDED] 後段：28mm → 43mm（全圓，VROTAT 360°）
    ! 用獨立 KP 避免共用問題
    ! ==========================================
    *get, KP_NUM, KP, , NUM, MAX
    KP_START2 = KP_NUM + 1
    NUMSTR, KP, KP_START2

    *get, LI_NUM, LINE, , NUM, MAX
    LI_START2 = LI_NUM + 1
    NUMSTR, LINE, LI_START2

    ! KP+0: 削平交界（軸上）— 獨立 KP
    ! KP+1: 削平交界（偏移 -side_perp）— 獨立 KP
    ! KP+2: 後端（偏移 -side_perp）
    ! KP+3: 後端（軸上）— 獨立 KP

    K, KP_START2,   fc_fx, fc_fy, fc_fz
    K, KP_START2+1, fc_fx + POLE_R*fc_nsx, fc_fy + POLE_R*fc_nsy, fc_fz
    K, KP_START2+2, fc_ex + POLE_R*fc_nsx, fc_ey + POLE_R*fc_nsy, fc_ez
    K, KP_START2+3, fc_ex, fc_ey, fc_ez

    L, KP_START2, KP_START2+1
    L, KP_START2+1, KP_START2+2
    L, KP_START2+2, KP_START2+3
    L, KP_START2+3, KP_START2

    *get, AR_NUM, AREA, , NUM, MAX
    AR_START2 = AR_NUM + 1
    NUMSTR, AREA, AR_START2
    AL, LI_START2, LI_START2+1, LI_START2+2, LI_START2+3

    VROTAT, AR_START2, ,,,, , KP_START2, KP_START2+3, , 4

    ALLSEL, ALL

    *msg, INFO, fc_pi
     Pole P%I built (D-shape + round)

*enddo

! ===== [ADDED] 安裝 block =====
! Upper block: 25×22×10mm, L型截面, 伸入7mm
! Lower block: 22×22×10mm, L型截面, 伸入4.5mm
! 寬邊朝 workspace, block 厚度沿 pole 軸

PENE_UP = 7.0*MM              ! 上層伸入量
PENE_DN = 4.5*MM              ! 下層伸入量
BLK_T   = 10.0*MM             ! block 厚度 (兩者相同)

*do, fc_pi, 1, 6, 1

    fc_incl = fc_ia(fc_pi)
    fc_azim = fc_ra(fc_pi)

    ! 軸方向
    fc_ax = cos(fc_incl)*cos(fc_azim)
    fc_ay = cos(fc_incl)*sin(fc_azim)
    fc_az = sin(fc_incl)

    ! up_perp (垂直軸,朝上)
    fc_ux = -sin(fc_incl)*cos(fc_azim)
    fc_uy = -sin(fc_incl)*sin(fc_azim)
    fc_uz = cos(fc_incl)

    ! side_perp (側向)
    fc_sx = sin(fc_azim)
    fc_sy = -cos(fc_azim)

    ! Tip 位置
    p1x = fc_tx(fc_pi)
    p1y = fc_ty(fc_pi)
    p1z = fc_tz(fc_pi)

    ! 判斷上下層 → 決定伸入量和 block 尺寸
    *if, fc_incl, GE, 0, THEN
        ! Upper pole → upper block (25×22×10)
        fc_pene = PENE_UP
        ! L型截面 (STEP coords → local: STEP_X=side, STEP_Y=up)
        ! Part1: side -0.5~12.5, up -11~11 (main body)
        ! Part2: side -12.5~-0.5, up -5~5 (extension)
        ! [MODIFIED] 平移 +0.25mm 讓 slot 中心對齊 pole 軸
        fc_s1a = -0.25*MM
        fc_s1b = 12.75*MM
        fc_u1a = -11.0*MM
        fc_u1b = 11.0*MM
        fc_s2a = -12.25*MM
        fc_s2b = -0.25*MM
        fc_u2a = -5.0*MM
        fc_u2b = 5.0*MM
    *else
        ! Lower pole → lower block (22×22×10)
        ! Part1: side 0~11, up -11~11 (main body)
        ! Part2: side -11~0, up -5~5 (extension)
        fc_pene = PENE_DN
        ! [MODIFIED] 平移 -2mm 讓 slot 中心(x=2)對齊 pole 軸
        fc_s1a = 2.0*MM       ! 4-2=2
        fc_s1b = 9.0*MM       ! 11-2=9
        fc_u1a = -11.0*MM
        fc_u1b = 11.0*MM
        fc_s2a = -13.0*MM     ! -11-2=-13
        fc_s2b = 2.0*MM       ! 4-2=2
        fc_u2a = -5.0*MM
        fc_u2b = 5.0*MM
    *endif

    ! Block 起點（沿 pole 軸，從 tip 算）
    fc_bstart = POLE_TOTAL_LEN - fc_pene

    ! [MODIFIED] Block 水平, global 座標, 不用 LOCAL CS
    ! Pole 尾端
    fc_endx = p1x + POLE_TOTAL_LEN*fc_ax
    fc_endy = p1y + POLE_TOTAL_LEN*fc_ay
    fc_endz = p1z + POLE_TOTAL_LEN*fc_az

    ! Entry point (workspace face, pole 尾端往回 PENE)
    fc_entx = fc_endx - fc_pene*fc_ax
    fc_enty = fc_endy - fc_pene*fc_ay
    fc_entz = fc_endz - fc_pene*fc_az

    ! Block Z 範圍 + XY 中心
    *if, fc_incl, GE, 0, THEN
        ! Upper: entry=bottom, outer=top
        fc_zbot = fc_entz
        fc_ztop = fc_entz + BLK_T
        ! Block 中心 = pole 軸在 outer face (top) 的 XY
        ! outer = entry + (BLK_T/sin(tilt))*axis
        fc_dt = BLK_T/sin(TILT_UP)
        fc_cx = fc_entx + fc_dt*fc_ax
        fc_cy = fc_enty + fc_dt*fc_ay
    *else
        ! Lower: pole 從側面穿過 block → block 垂直居中在 pole 軸上
        fc_zbot = fc_endz - BLK_T/2
        fc_ztop = fc_endz + BLK_T/2
        ! Block 中心 = pole 尾端 XY
        fc_cx = fc_endx
        fc_cy = fc_endy
    *endif

    ! XY 方向向量 (水平面, 朝 workspace = azim+180°)
    fc_twx = -cos(fc_azim)
    fc_twy = -sin(fc_azim)
    fc_sdx = sin(fc_azim)
    fc_sdy = -cos(fc_azim)

    ! --- Block Part 1: 8 角點 (global) ---
    *get, KP_NUM, KP, , NUM, MAX
    *if, KP_NUM, LT, 1, THEN
        KP_NUM = 0
    *endif
    fc_bkp = KP_NUM + 1
    NUMSTR, KP, fc_bkp

    ! Bottom face (z=fc_zbot), 4 corners: (s1a,u1a) (s1b,u1a) (s1b,u1b) (s1a,u1b)
    K,fc_bkp,  fc_cx+fc_s1a*fc_twx+fc_u1a*fc_sdx, fc_cy+fc_s1a*fc_twy+fc_u1a*fc_sdy, fc_zbot
    K,fc_bkp+1,fc_cx+fc_s1b*fc_twx+fc_u1a*fc_sdx, fc_cy+fc_s1b*fc_twy+fc_u1a*fc_sdy, fc_zbot
    K,fc_bkp+2,fc_cx+fc_s1b*fc_twx+fc_u1b*fc_sdx, fc_cy+fc_s1b*fc_twy+fc_u1b*fc_sdy, fc_zbot
    K,fc_bkp+3,fc_cx+fc_s1a*fc_twx+fc_u1b*fc_sdx, fc_cy+fc_s1a*fc_twy+fc_u1b*fc_sdy, fc_zbot
    ! Top face (z=fc_ztop)
    K,fc_bkp+4,fc_cx+fc_s1a*fc_twx+fc_u1a*fc_sdx, fc_cy+fc_s1a*fc_twy+fc_u1a*fc_sdy, fc_ztop
    K,fc_bkp+5,fc_cx+fc_s1b*fc_twx+fc_u1a*fc_sdx, fc_cy+fc_s1b*fc_twy+fc_u1a*fc_sdy, fc_ztop
    K,fc_bkp+6,fc_cx+fc_s1b*fc_twx+fc_u1b*fc_sdx, fc_cy+fc_s1b*fc_twy+fc_u1b*fc_sdy, fc_ztop
    K,fc_bkp+7,fc_cx+fc_s1a*fc_twx+fc_u1b*fc_sdx, fc_cy+fc_s1a*fc_twy+fc_u1b*fc_sdy, fc_ztop

    V,fc_bkp,fc_bkp+1,fc_bkp+2,fc_bkp+3,fc_bkp+4,fc_bkp+5,fc_bkp+6,fc_bkp+7

    ! --- Block Part 2: 8 角點 ---
    *get, KP_NUM, KP, , NUM, MAX
    fc_bkp2 = KP_NUM + 1
    NUMSTR, KP, fc_bkp2

    K,fc_bkp2,  fc_cx+fc_s2a*fc_twx+fc_u2a*fc_sdx, fc_cy+fc_s2a*fc_twy+fc_u2a*fc_sdy, fc_zbot
    K,fc_bkp2+1,fc_cx+fc_s2b*fc_twx+fc_u2a*fc_sdx, fc_cy+fc_s2b*fc_twy+fc_u2a*fc_sdy, fc_zbot
    K,fc_bkp2+2,fc_cx+fc_s2b*fc_twx+fc_u2b*fc_sdx, fc_cy+fc_s2b*fc_twy+fc_u2b*fc_sdy, fc_zbot
    K,fc_bkp2+3,fc_cx+fc_s2a*fc_twx+fc_u2b*fc_sdx, fc_cy+fc_s2a*fc_twy+fc_u2b*fc_sdy, fc_zbot
    K,fc_bkp2+4,fc_cx+fc_s2a*fc_twx+fc_u2a*fc_sdx, fc_cy+fc_s2a*fc_twy+fc_u2a*fc_sdy, fc_ztop
    K,fc_bkp2+5,fc_cx+fc_s2b*fc_twx+fc_u2a*fc_sdx, fc_cy+fc_s2b*fc_twy+fc_u2a*fc_sdy, fc_ztop
    K,fc_bkp2+6,fc_cx+fc_s2b*fc_twx+fc_u2b*fc_sdx, fc_cy+fc_s2b*fc_twy+fc_u2b*fc_sdy, fc_ztop
    K,fc_bkp2+7,fc_cx+fc_s2a*fc_twx+fc_u2b*fc_sdx, fc_cy+fc_s2a*fc_twy+fc_u2b*fc_sdy, fc_ztop

    V,fc_bkp2,fc_bkp2+1,fc_bkp2+2,fc_bkp2+3,fc_bkp2+4,fc_bkp2+5,fc_bkp2+6,fc_bkp2+7

    ! VADD
    *get, fc_bv2, VOLU, 0, NUM, MAX
    fc_bv1 = fc_bv2 - 1
    VADD, fc_bv1, fc_bv2

    ALLSEL, ALL

    *msg, INFO, fc_pi
     Block for P%I built

*enddo

! ===== [ADDED] 安裝線圈 =====
! 線圈軸垂直 Z, XY = block 中心
! 簡化繞線區: R_inner=6, R_outer=10, height=14mm
! 上層: z = block_bottom ~ block_bottom+17mm (assembly 關係)
! 下層: z = block_bottom-17mm ~ block_bottom

COIL_RI = 4.0*MM              ! [MODIFIED] 貼合導柱 R4 (內徑=導柱半徑)
COIL_RO = 7.0*MM              ! [MODIFIED] 外徑 7 (厚度3同long2016)
COIL_H  = 7.0*MM              ! [MODIFIED] long2016 線圈高 7mm
BLK_YOKE_GAP = 14.0*MM        ! [ADDED] upper block頂->yoke底 間距(定位yoke,與線圈高解耦)

*do, fc_pi, 1, 6, 1

    fc_incl = fc_ia(fc_pi)
    fc_azim = fc_ra(fc_pi)

    fc_ax = cos(fc_incl)*cos(fc_azim)
    fc_ay = cos(fc_incl)*sin(fc_azim)
    fc_az = sin(fc_incl)

    p1x = fc_tx(fc_pi)
    p1y = fc_ty(fc_pi)
    p1z = fc_tz(fc_pi)

    ! Block 中心 (跟步驟 3 一樣)
    fc_endx = p1x + POLE_TOTAL_LEN*fc_ax
    fc_endy = p1y + POLE_TOTAL_LEN*fc_ay
    fc_endz = p1z + POLE_TOTAL_LEN*fc_az

    *if, fc_incl, GE, 0, THEN
        fc_pene = PENE_UP
        fc_entx = fc_endx - fc_pene*fc_ax
        fc_enty = fc_endy - fc_pene*fc_ay
        fc_entz = fc_endz - fc_pene*fc_az
        fc_ztop_blk = fc_entz + BLK_T
        fc_dt = BLK_T/sin(TILT_UP)
        fc_cx = fc_entx + fc_dt*fc_ax
        fc_cy = fc_enty + fc_dt*fc_ay
    *else
        fc_cx = fc_endx
        fc_cy = fc_endy
        fc_ztop_blk = fc_endz + BLK_T/2
    *endif
    ! Coil Z 在 block 上方
    fc_cz1 = fc_ztop_blk
    fc_cz2 = fc_ztop_blk + COIL_H

    ! 截面 KP + 軸 KP
    *get, KP_NUM, KP, , NUM, MAX
    *if, KP_NUM, LT, 1, THEN
        KP_NUM = 0
    *endif
    fc_ckp = KP_NUM + 1
    NUMSTR, KP, fc_ckp

    K, fc_ckp,   fc_cx+COIL_RI, fc_cy, fc_cz1
    K, fc_ckp+1, fc_cx+COIL_RO, fc_cy, fc_cz1
    K, fc_ckp+2, fc_cx+COIL_RO, fc_cy, fc_cz2
    K, fc_ckp+3, fc_cx+COIL_RI, fc_cy, fc_cz2
    K, fc_ckp+4, fc_cx, fc_cy, fc_cz1
    K, fc_ckp+5, fc_cx, fc_cy, fc_cz2

    *get, LI_NUM, LINE, , NUM, MAX
    *if, LI_NUM, LT, 1, THEN
        LI_NUM = 0
    *endif
    fc_cli = LI_NUM + 1
    NUMSTR, LINE, fc_cli
    L,fc_ckp,fc_ckp+1
    L,fc_ckp+1,fc_ckp+2
    L,fc_ckp+2,fc_ckp+3
    L,fc_ckp+3,fc_ckp
    *get, AR_NUM, AREA, , NUM, MAX
    fc_car = AR_NUM + 1
    NUMSTR, AREA, fc_car
    AL,fc_cli,fc_cli+1,fc_cli+2,fc_cli+3
    VROTAT,fc_car,,,,,,fc_ckp+4,fc_ckp+5,,4

    ALLSEL, ALL

    *msg, INFO, fc_pi
     Coil for P%I built

*enddo

! ===== [ADDED] 安裝 Yoke =====
! 環形板, 中心在原點, 軸 Z, 在上層 coil 頂面上方
! R_inner=40, R_outer=52, 厚度 2mm

YOKE_RI = 38.0*MM             ! [MODIFIED] 內徑縮小讓導柱不露出
YOKE_RO = 62.5*MM             ! [MODIFIED] 從導磁鐵環.STEP 提取
YOKE_T  = 2.0*MM

! 上層 coil top z: 需要從上層 block 計算
! 上層 entry_z 已在 coil 迴圈中算過, 重新算一次
! 所有上層 pole 的 fc_endz 相同, 取 P2 的
fc_up_endz = fc_tz(2) + POLE_TOTAL_LEN*sin(TILT_UP)
fc_up_entz = fc_up_endz - PENE_UP*sin(TILT_UP)
fc_up_blk_top = fc_up_entz + BLK_T
fc_yoke_zbot = fc_up_blk_top + BLK_YOKE_GAP   ! [MODIFIED] 用 gap 定位 yoke(不用 coil 高)
fc_yoke_ztop = fc_yoke_zbot + YOKE_T

! Yoke 截面 KP (矩形: R_inner~R_outer, zbot~ztop)
*get, KP_NUM, KP, , NUM, MAX
*if, KP_NUM, LT, 1, THEN
    KP_NUM = 0
*endif
fc_ykp = KP_NUM + 1
NUMSTR, KP, fc_ykp

K, fc_ykp,   YOKE_RI, 0, fc_yoke_zbot
K, fc_ykp+1, YOKE_RO, 0, fc_yoke_zbot
K, fc_ykp+2, YOKE_RO, 0, fc_yoke_ztop
K, fc_ykp+3, YOKE_RI, 0, fc_yoke_ztop
! 軸 KP (Z 軸, 通過原點)
K, fc_ykp+4, 0, 0, fc_yoke_zbot
K, fc_ykp+5, 0, 0, fc_yoke_ztop

*get, LI_NUM, LINE, , NUM, MAX
*if, LI_NUM, LT, 1, THEN
    LI_NUM = 0
*endif
fc_yli = LI_NUM + 1
NUMSTR, LINE, fc_yli

L, fc_ykp, fc_ykp+1
L, fc_ykp+1, fc_ykp+2
L, fc_ykp+2, fc_ykp+3
L, fc_ykp+3, fc_ykp

*get, AR_NUM, AREA, , NUM, MAX
*if, AR_NUM, LT, 1, THEN
    AR_NUM = 0
*endif
fc_yar = AR_NUM + 1
NUMSTR, AREA, fc_yar
AL, fc_yli, fc_yli+1, fc_yli+2, fc_yli+3

VROTAT, fc_yar, ,,,, , fc_ykp+4, fc_ykp+5, , 4

ALLSEL, ALL

*msg, INFO
 Yoke built

! ===== [ADDED] 安裝磁場導柱 =====
! 3 根, 連接 yoke → 下層 block, 穿過上層 coil 中心孔
! 簡化為圓柱 R=4mm, 從 lower_block_top 到 yoke_bottom
! XY = 下層 block 中心 (P1, P3, P6)

GP_R = 4.0*MM                 ! 導柱半徑 (取最大截面)
GP_H = 46.0*MM                ! 導柱總高 46mm
GP_YOKE_R = 57.5*MM           ! [ADDED] 導柱在 yoke 上的徑向位置 (螺絲孔)

! 下層 block top z (所有下層相同)
fc_lo_endz = fc_tz(1) + POLE_TOTAL_LEN*sin(-TILT_DN)
fc_lo_blk_top = fc_lo_endz + BLK_T/2

! 下層 pole 索引: P1=1, P3=3, P6=6
*dim, fc_gpi, , 3
fc_gpi(1) = 1
fc_gpi(2) = 3
fc_gpi(3) = 6

*do, fc_gi, 1, 3, 1
    fc_idx = fc_gpi(fc_gi)
    fc_azim = fc_ra(fc_idx)

    ! 導柱 XY = 下層 block 中心
    fc_ax = cos(-TILT_DN)*cos(fc_azim)
    fc_ay = cos(-TILT_DN)*sin(fc_azim)
    fc_gcx = fc_tx(fc_idx) + POLE_TOTAL_LEN*fc_ax
    fc_gcy = fc_ty(fc_idx) + POLE_TOTAL_LEN*fc_ay

    ! 導柱 Z: lower_block_top → yoke_bottom
    ! [MODIFIED] 導柱頂端接 yoke 底面，向下延伸 46mm
    fc_gz2 = fc_yoke_zbot             ! 導柱頂 = yoke 底面
    fc_gz1 = fc_yoke_zbot - GP_H      ! 導柱底 = yoke 底 - 46mm

    ! 截面 KP (矩形 0~R, z1~z2) + 軸 KP
    *get, KP_NUM, KP, , NUM, MAX
    *if, KP_NUM, LT, 1, THEN
        KP_NUM = 0
    *endif
    fc_gkp = KP_NUM + 1
    NUMSTR, KP, fc_gkp

    K, fc_gkp,   fc_gcx+GP_R, fc_gcy, fc_gz1
    K, fc_gkp+1, fc_gcx+GP_R, fc_gcy, fc_gz2
    K, fc_gkp+2, fc_gcx,      fc_gcy, fc_gz2
    K, fc_gkp+3, fc_gcx,      fc_gcy, fc_gz1

    *get, LI_NUM, LINE, , NUM, MAX
    *if, LI_NUM, LT, 1, THEN
        LI_NUM = 0
    *endif
    fc_gli = LI_NUM + 1
    NUMSTR, LINE, fc_gli

    L, fc_gkp, fc_gkp+1
    L, fc_gkp+1, fc_gkp+2
    L, fc_gkp+2, fc_gkp+3
    L, fc_gkp+3, fc_gkp

    *get, AR_NUM, AREA, , NUM, MAX
    *if, AR_NUM, LT, 1, THEN
        AR_NUM = 0
    *endif
    fc_gar = AR_NUM + 1
    NUMSTR, AREA, fc_gar
    AL, fc_gli, fc_gli+1, fc_gli+2, fc_gli+3

    ! VROTAT 繞垂直軸 (通過導柱中心)
    VROTAT, fc_gar, ,,,, , fc_gkp+2, fc_gkp+3, , 4

    ALLSEL, ALL

    *msg, INFO, fc_gi
     Guide post %I built

*enddo

! ===== [ADDED] 上層 Core =====
! 3 根, 連接 yoke → 上層 block, R=4mm
! XY = 上層 block 中心 (P2, P4, P5)

fc_up_blk_top2 = fc_up_entz + BLK_T

*dim, fc_upi, , 3
fc_upi(1) = 2
fc_upi(2) = 4
fc_upi(3) = 5

*do, fc_ui, 1, 3, 1
    fc_idx = fc_upi(fc_ui)
    fc_azim = fc_ra(fc_idx)

    ! 上層 core XY = 上層 block 中心
    fc_pene_tmp = PENE_UP
    fc_ax_tmp = cos(TILT_UP)*cos(fc_azim)
    fc_ay_tmp = cos(TILT_UP)*sin(fc_azim)
    fc_endx_tmp = fc_tx(fc_idx) + POLE_TOTAL_LEN*fc_ax_tmp
    fc_endy_tmp = fc_ty(fc_idx) + POLE_TOTAL_LEN*fc_ay_tmp
    fc_endz_tmp = fc_tz(fc_idx) + POLE_TOTAL_LEN*sin(TILT_UP)
    fc_entx_tmp = fc_endx_tmp - fc_pene_tmp*fc_ax_tmp
    fc_enty_tmp = fc_endy_tmp - fc_pene_tmp*fc_ay_tmp
    fc_dt_tmp = BLK_T/sin(TILT_UP)
    fc_ucx = fc_entx_tmp + fc_dt_tmp*fc_ax_tmp
    fc_ucy = fc_enty_tmp + fc_dt_tmp*fc_ay_tmp

    ! Core Z: 上層 block top → yoke bottom
    fc_ucz1 = fc_up_blk_top2
    fc_ucz2 = fc_yoke_zbot

    ! 截面 + 軸 KP
    *get, KP_NUM, KP, , NUM, MAX
    *if, KP_NUM, LT, 1, THEN
        KP_NUM = 0
    *endif
    fc_uckp = KP_NUM + 1
    NUMSTR, KP, fc_uckp

    K,fc_uckp,  fc_ucx+GP_R, fc_ucy, fc_ucz1
    K,fc_uckp+1,fc_ucx+GP_R, fc_ucy, fc_ucz2
    K,fc_uckp+2,fc_ucx,      fc_ucy, fc_ucz2
    K,fc_uckp+3,fc_ucx,      fc_ucy, fc_ucz1

    *get, LI_NUM, LINE, , NUM, MAX
    fc_ucli = LI_NUM + 1
    NUMSTR, LINE, fc_ucli
    L,fc_uckp,fc_uckp+1
    L,fc_uckp+1,fc_uckp+2
    L,fc_uckp+2,fc_uckp+3
    L,fc_uckp+3,fc_uckp

    *get, AR_NUM, AREA, , NUM, MAX
    fc_ucar = AR_NUM + 1
    NUMSTR, AREA, fc_ucar
    AL,fc_ucli,fc_ucli+1,fc_ucli+2,fc_ucli+3

    VROTAT,fc_ucar,,,,,,fc_uckp+2,fc_uckp+3,,4

    ALLSEL, ALL

    *msg, INFO, fc_ui
     Upper core %I built

*enddo

! ===== 整理與匯出 =====
CSYS, 0
NUMCMP, VOLU
NUMCMP, AREA
NUMCMP, LINE
NUMCMP, KP

*get, fc_nvf, VOLU, 0, NUM, MAX
*msg, INFO, fc_nvf
 Final: %I volumes

! [MODIFIED] commented out SAVE to prevent .db pollution in IGES folder
!**** SAVE, 'Full_Assembly_filleted', 'db'

! [ADDED-BASEGAP] === 6-pole 200um BLOCK-ONLY air-gap slab (-> mu_r=1 in sim) ===
! [MODIFIED 2026-07-09 EXPERIMENT] Robust cut = VADD all steel into 1 body, then per-pole finite
!   BLOCK (WPROTA to pole azim, covers only that pole's base slab) VSBV,KEEP. PORTED from the mesh
!   deck (MT_Mesh_Graded_BaseGap.txt) because the old VSBW double-blade could NOT isolate P6
!   (azim 240) at the inner radial 40 (last-processed pole -> boolean interference). BLOCK+VSBV
!   cuts all 6 cleanly and matches the sim topology (steel merged into 1 body).
!   Lower azim 0/120/240 @ radial GLOW_R=40mm = INSIDE the guide-post feed (x~43.2) in the Part1
!   SERIES steel, PAST the shortened lower rod (ROD_LEN_LO -> cap ~38.5mm) so the rod no longer
!   bridges/short-circuits the gap -> blocking the series path drops tip |B| (normal, like upper).
!   Upper azim 60/180/300 @ radial 44.43mm unchanged. Units = inch (MM=1/25.4); 200um sweep = 0.2mm.
ALLSEL, ALL
VADD, ALL
NUMCMP, VOLU
ALLSEL, ALL
*GET, vsteel, VOLU, , NUM, MAX          ! merged steel = single volume
*dim, gblk, , 6
*do, gpl, 1, 6
    *if, gpl, le, 3, then
        gaz = 120*(gpl-1)
        gxa = GLOW_R*MM
        gxb = (GLOW_R+0.2)*MM
        ! [MODIFIED EXPERIMENT] z = lower block z EXACTLY (centered on pole end) -> z-height = BLK_T = 10mm -> face 10x10 = 100mm2 exactly
        gzc = -fc_h + POLE_TOTAL_LEN*sin(-TILT_DN)
        gza = gzc - BLK_T/2
        gzb = gzc + BLK_T/2
        ghw = GAP_HW_LO*MM              ! lower half-width 5mm (10mm wide, inside 22mm Part1 -> partial, ~6mm bridge each side)
    *else
        gaz = 60 + 120*(gpl-4)
        gxa = 44.43*MM
        gxb = 44.63*MM
        ! [MODIFIED EXPERIMENT] z = upper block z EXACTLY (entry-based) -> z-height = BLK_T = 10mm -> face 10x10 = 100mm2 exactly
        gzc = fc_h + POLE_TOTAL_LEN*sin(TILT_UP) - PENE_UP*sin(TILT_UP)
        gza = gzc
        gzb = gzc + BLK_T
        ghw = 5.0*MM                    ! = Part2 half-width (10mm neck) -> full sever + exactly 100mm2
    *endif
    WPLANE, 1,0,0,0,,,,,,
    WPcsys, -1, 0
    WPROTA, gaz
    BLOCK, gxa, gxb, -ghw, ghw, gza, gzb
    *GET, gblk(gpl), VOLU, , NUM, MAX
*enddo
WPcsys, -1, 0
vblk_lo = gblk(1)
vblk_hi = gblk(6)
VSEL, S, VOLU, , vblk_lo, vblk_hi       ! select 6 BLOCK tools
VSBV, vsteel, ALL, , , KEEP             ! steel minus 6 BLOCK, KEEP slabs (= air in sim)
ALLSEL, ALL
CSYS, 0
WPCSYS, -1, 0
NUMCMP, VOLU
! --- verify slab per pole: KEEP'd tool BLOCK (full 0.2 x 24 x 12/13mm, un-clipped since no
!     VOVLAP in geom) -> expect nvol=1 each, vol ~3.5e-3 in^3 (lower) / ~3.8e-3 in^3 (upper).
!     Key check = nvol=1 for ALL 6 (incl P6 azim 240, which the old VSBW failed to cut). ---
*do, gpl, 1, 6
    *if, gpl, le, 3, then
        gaz = 120*(gpl-1)
        gza = -10*MM
        gzb = 2*MM
        gra = GLOW_R*MM
        grb = (GLOW_R+0.2)*MM
    *else
        gaz = 60 + 120*(gpl-4)
        gza = 19*MM
        gzb = 32*MM
        gra = 44.43*MM
        grb = 44.63*MM
    *endif
    ALLSEL, ALL
    LOCAL, 15, 0, 0,0,0, gaz
    CSYS, 15
    VSEL, S, LOC, X, gra, grb
    VSEL, R, LOC, Z, gza, gzb
    VSEL, R, LOC, Y, -13*MM, 13*MM
    CSYS, 0
    CSDELE, 15
    VSUM
    *GET, gsc, VOLU, 0, COUNT
    *GET, gsv, VOLU, 0, VOLU
    *msg, INFO, gaz, gsc, gsv
 SLAB azim=%G nvol=%I vol_in3=%G
*enddo
ALLSEL, ALL

! [ADDED-BASEGAP] IGES out (flag 6; patch to 1 for SolidWorks separately)
ALLSEL, ALL
IGESOUT, 'G:\my_workspace\FEM_sim\magnetic_sim\ANSYS\main\model_check\hung_hexapole\hung_full_assembly_basegap', 'iges'

FINISH
/EXIT, NOSAV

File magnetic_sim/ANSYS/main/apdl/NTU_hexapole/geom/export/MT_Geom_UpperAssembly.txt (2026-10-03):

! ============================================================================
! NTU_hexapole — UPPER-layer FULL ASSEMBLY (upper_assembly): 3 磁極 + 6 導柱 + yoke
! ----------------------------------------------------------------------------
! Source CAD = CAD_model/NTU_hexapole/STEP/建棋模擬_上層/{上層組合.STEP, YOKE.step}.
!   Canonical frame via T = Rz(180 about world z)+z-9.55 (pole0 canonical, == pole_assembly).
!   Dims OCC-extracted from the CAD (under T):
!     3 磁極 : flat 0.25mm, 9-seg profile, at 0/120/240 deg.
!     6 導柱 : SOLID stepped cyl, radius 20.5 at 0/60/120/180/240/300 deg; step at z=11.25.
!              base z: 0/120/240deg -> 0.25 ; 60/180/300deg -> -0.5 ; top z 17.25.
!              r2.5 (base->11.25) + r2.49 (11.25->17.25).
!     yoke   : rounded-rect plate 59.8x53.8 (r5 corners) + central rounded-rect cutout
!              31x20.5 (r5) + 6 post-holes r2.5 @radius20.5 ; thickness 5.5 @z[11.25,16.75].
!              deck uses SHARP rectangles (r5 corner fillets omitted, minor) per STEP dims.
!   STEP delivery (exact CAD) = make_upper_assembly_step.py -> upper_assembly.step.
!   model_check gets STEP only (no IGES) per user; this deck's IGESOUT goes to IGES/.
! [MODIFIED 2026-07-11] 3-pole -> 3-pole + 6-post + yoke.
! ============================================================================

! [MODIFIED 2026-08-17] /CWD removed - db/geom/ retired; working dir now comes from launcher -dir

Finish
/cle
/PREP7
*afun, DEG

UNIT_MM = 1
*if, UNIT_MM, eq, 1, then
    SC = 1.0
    BTOL, 1e-4
*else
    SC = 1.0e-3
    BTOL, 1e-7
*endif
/UNITS, MKS

TH    = 0.25*SC
POSTX = 20.5*SC
PR    = 20.5*SC          ! post/hole axis radius

! ============================================================================
! PART A — 3 磁極（WPROTA 0/120/240 deg）
! ============================================================================
*do, pole, 1, 3
	ANG = (pole-1)*120
	WPLANE, 1,0,0,0
	WPcsys,-1,0
	WPROTA, ANG
	CSYS, 4
	*get, KB, KP, , NUM, MAX
	K, KB+1,  0.357*SC,  0.005*SC, 0
	K, KB+2,  0.353*SC,  0.000*SC, 0
	K, KB+3,  0.357*SC, -0.005*SC, 0
	K, KB+4,  4.509*SC, -0.523*SC, 0
	K, KB+5,  6.175*SC, -0.877*SC, 0
	K, KB+6, 19.048*SC, -4.784*SC, 0
	K, KB+7, 19.048*SC,  4.784*SC, 0
	K, KB+8,  6.175*SC,  0.877*SC, 0
	K, KB+9,  4.509*SC,  0.523*SC, 0
	K, KB+10,25.500*SC,  0.000*SC, 0
	K, KB+11, 0.358*SC,  0.000*SC, 0
	K, KB+12, 3.271*SC,-10.446*SC, 0
	K, KB+13, 3.271*SC, 10.446*SC, 0
	K, KB+14,20.500*SC,  0.000*SC, 0
	*get, LB, LINE, , NUM, MAX
	LARC, KB+1, KB+2, KB+11, 0.005*SC
	LARC, KB+2, KB+3, KB+11, 0.005*SC
	L,    KB+3, KB+4
	LARC, KB+4, KB+5, KB+12, 10.0*SC
	L,    KB+5, KB+6
	LARC, KB+6, KB+10, KB+14, 5.0*SC
	LARC, KB+10, KB+7, KB+14, 5.0*SC
	L,    KB+7, KB+8
	LARC, KB+8, KB+9, KB+13, 10.0*SC
	L,    KB+9, KB+1
	AL, LB+1, LB+2, LB+3, LB+4, LB+5, LB+6, LB+7, LB+8, LB+9, LB+10
	*get, AB, AREA, , NUM, MAX
	VEXT, AB, , , 0, 0, TH
	KDELE, KB+11, KB+14, 1
	CSYS, 0
*enddo

! ============================================================================
! PART B — 6 導柱（radius 20.5，角 0/60/120/180/240/300；base z 交替 0.25 / -0.5）
! ============================================================================
*dim, PANG, , 6
PANG(1)=0 $ PANG(2)=60 $ PANG(3)=120 $ PANG(4)=180 $ PANG(5)=240 $ PANG(6)=300
*dim, PBZ, , 6
PBZ(1)=0.25 $ PBZ(2)=-0.5 $ PBZ(3)=0.25 $ PBZ(4)=-0.5 $ PBZ(5)=0.25 $ PBZ(6)=-0.5
*do, ip, 1, 6
	PX = PR*cos(PANG(ip))
	PY = PR*sin(PANG(ip))
	BZ = PBZ(ip)*SC
	WPLANE, 1,0,0,0
	WPcsys,-1,0
	WPOFFS, PX, PY, 0
	CYLIND, 2.50*SC, , BZ,        11.25*SC     ! r2.5  base -> 11.25
	CYLIND, 2.49*SC, , 11.25*SC,  17.25*SC     ! r2.49 11.25 -> 17.25
	WPOFFS, -PX, -PY, 0
*enddo

! ============================================================================
! PART C — yoke（外盤 − 中心 cutout − 6 孔；厚 5.5 @z[11.25,16.75]）
! ============================================================================
CSYS, 0
WPLANE, 1,0,0,0
WPcsys,-1,0
BLOCK, -29.900*SC, 29.900*SC, -26.900*SC, 26.900*SC, 11.25*SC, 16.75*SC   ! 外盤(sharp) = V_OUT
*get, V_OUT, VOLU, , NUM, MAX
BLOCK, -15.500*SC, 15.500*SC, -10.254*SC, 10.254*SC, 11.25*SC, 16.75*SC   ! 中心 cutout = V_OUT+1
*do, ih, 1, 6                                  ! 6 導柱孔 = V_OUT+2 .. V_OUT+7（先全建、序號連續）
	HX = PR*cos(PANG(ih))
	HY = PR*sin(PANG(ih))
	WPLANE, 1,0,0,0
	WPcsys,-1,0
	WPOFFS, HX, HY, 0
	CYLIND, 2.50*SC, , 11.25*SC, 16.75*SC      ! 導柱孔 r2.5
	WPOFFS, -HX, -HY, 0
*enddo
! 一次 VSBV：外盤 − (cutout + 6 孔)；選 V_OUT..V_OUT+7 後 VSBV ALL（避免序號重用踩坑）
VSEL, S, VOLU, , V_OUT, V_OUT+7
VSBV, V_OUT, ALL
ALLSEL, ALL

! ---- finalise + IGES（→ IGES/，不進 model_check）---------------------------
ALLSEL, ALL
NUMCMP, ALL

*if, UNIT_MM, eq, 1, then
    IGESOUT, 'G:\my_workspace\FEM_sim\magnetic_sim\ANSYS\main\model_check\NTU_hexapole\upper_assembly_mm', 'iges'
! [MODIFIED 2026-08-17] metre-unit IGESOUT removed - only mm IGES is needed
*endif

SAVE

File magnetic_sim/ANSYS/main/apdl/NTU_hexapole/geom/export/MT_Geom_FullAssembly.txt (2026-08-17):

! ============================================================================
! NTU_hexapole — FULL ASSEMBLY (整體 model；階段性建構)
!   命名 full_assembly = 整體 model；yoke/coil 之後階段擴充「此」deck。
!   Source CAD = CAD_model/NTU_hexapole/STEP/總組合.STEP（OCP 世界座標量測，見 full_assembly_params.md）。
!   階段① 6 磁極 = 兩平面薄板層（各厚 0.25mm，對齊 總組合.STEP 原點、不平移到 z=0）：
!     下層 z=[8.80,9.05] @ WPROTA 0/120/240° ; 上層 z=[9.55,9.80] @ WPROTA 60/180/300°。
!     輪廓同 pole_params.md（9 段環、尖端 5µm 圓角、遠端凸弧 r5）；建法沿用 MT_Geom_UpperAssembly.txt PART A。
!   階段② 6 導柱 = 垂直實心圓柱 r2.5，沿磁極方位軸 r=20.5，底坐磁極頂面、頂齊平 z=26.80：
!     長導柱 ×3 @0/120/240° z[9.05,26.80]（長17.75）；短導柱 ×3 @60/180/300° z[9.80,26.80]（長17.00）。
!   階段③ yoke = rounded-rect 外盤 59.8×53.8 − 中心 cutout 31×20.5 − 6 孔 r2.5（VSBV）：
!     忠實 r5 圓角（外盤 4 角 + cutout 4 角）；厚 5.5 @ z[20.80,26.30]；6 孔對齊導柱 → 1 volume。
!   階段④ 6 襯套 = 凸緣頂帽狀空心襯套（bore r2.5 / tube 外徑 r3.5 / flange 外徑 r7.5，總組合.STEP 尺寸）：
!     6 個在 r=20.5 @ 0/60/…/300°、全垂直、z[15.60,20.80]（flange z[15.60,16.60]、tube z[16.60,20.80]）；
!     套上 6 導柱（導柱 r2.5 填內孔）；每個 = (flange VADD tube) VSBV bore → 空心環。
!   STEP delivery = make_full_assembly_step.py -> model_check/NTU_hexapole/full_assembly.step（不出 IGES）。
! [ADDED 2026-07-15] 階段①磁極 + 階段②導柱 + 階段③yoke；[ADDED 2026-07-17] 階段④6襯套；材料/元素/BC/coil 之後階段加。
! ============================================================================

! [MODIFIED 2026-08-17] /CWD removed - db/geom/ retired; working dir now comes from launcher -dir

Finish
/cle
/PREP7
*afun, DEG

UNIT_MM = 1                  ! 1 = mm (SC=1.0，與 NTU UpperAssembly 一致；5µm 圓角在公尺尺度 LARC 建不起來) ; 0 = 公尺 MKS
*if, UNIT_MM, eq, 1, then
    SC = 1.0
    BTOL, 1e-4
*else
    SC = 1.0e-3
    BTOL, 1e-7
*endif
/UNITS, MKS

TH  = 0.25*SC                ! 板厚 (VEXT 沿 +z)
ZLO = 8.80*SC               ! 下層板底 z（總組合.STEP 世界座標）
ZHI = 9.55*SC               ! 上層板底 z

! [ADDED 階段②] 6 導柱參數（guide posts；世界座標 mm）
RPOST = 20.5*SC             ! 導柱徑向位置（沿各磁極方位軸；貼近凸端 x25.5 略內縮）
RP    = 2.5*SC              ! 導柱半徑（尖端簡化成整根 r2.5 實心，忽略 CAD r2.49 尖段）
ZTOP  = 26.80*SC            ! 導柱頂端（6 根齊平）
ZPLO  = 9.05*SC             ! 下層磁極板頂面 = 長導柱底（長17.75）
ZPHI  = 9.80*SC             ! 上層磁極板頂面 = 短導柱底（長17.00）

! [ADDED 階段③] yoke 參數（磁軛盤；世界座標 mm；忠實 r5 圓角）
YRR  = 5.0*SC               ! 外盤 + cutout 四角圓角半徑 r5
ZYB  = 20.80*SC             ! yoke 底 z
ZYT  = 26.30*SC             ! yoke 頂 z（厚 5.5）
YHR  = 2.5*SC               ! 6 導柱孔半徑（= 導柱 r2.5）

! ============================================================================
! 6 磁極：下層(0/120/240°@ZLO) + 上層(60/180/300°@ZHI)；每極一 volume
!   輪廓 K/L/LARC/AL 原封沿用 UpperAssembly PART A；只加層 z 偏移 (WPOFFS) 與上層 +60° 相位。
! ============================================================================
*do, layer, 1, 2
    *if, layer, eq, 1, then
        ZB = ZLO
        A0 = 0
    *else
        ZB = ZHI
        A0 = 60
    *endif
    *do, pole, 1, 3
        ANG = A0 + (pole-1)*120
        WPLANE, 1,0,0,0
        WPCSYS, -1, 0            ! WP = global cartesian
        WPOFFS, 0, 0, ZB        ! WP 原點移到 (0,0,ZB) = 該層板底
        WPROTA, ANG             ! 繞 WP z 轉 ANG（*afun DEG）
        CSYS, 4                 ! 用 WP 座標系下點
        *get, KB, KP, , NUM, MAX
        K, KB+1,  0.357*SC,  0.005*SC, 0
        K, KB+2,  0.353*SC,  0.000*SC, 0
        K, KB+3,  0.357*SC, -0.005*SC, 0
        K, KB+4,  4.509*SC, -0.523*SC, 0
        K, KB+5,  6.175*SC, -0.877*SC, 0
        K, KB+6, 19.048*SC, -4.784*SC, 0
        K, KB+7, 19.048*SC,  4.784*SC, 0
        K, KB+8,  6.175*SC,  0.877*SC, 0
        K, KB+9,  4.509*SC,  0.523*SC, 0
        K, KB+10,25.500*SC,  0.000*SC, 0
        K, KB+11, 0.358*SC,  0.000*SC, 0        ! 尖端圓角中心
        K, KB+12, 3.271*SC,-10.446*SC, 0        ! 下凹弧圓心
        K, KB+13, 3.271*SC, 10.446*SC, 0        ! 上凹弧圓心
        K, KB+14,20.500*SC,  0.000*SC, 0        ! 遠端凸弧圓心
        *get, LB, LINE, , NUM, MAX
        LARC, KB+1, KB+2, KB+11, 0.005*SC       ! 尖端圓角上
        LARC, KB+2, KB+3, KB+11, 0.005*SC       ! 尖端圓角下
        L,    KB+3, KB+4                         ! 下側直邊1
        LARC, KB+4, KB+5, KB+12, 10.0*SC        ! 下凹弧 r10
        L,    KB+5, KB+6                         ! 下側直邊2
        LARC, KB+6, KB+10, KB+14, 5.0*SC        ! 遠端凸弧 r5（拆兩段 <180）
        LARC, KB+10, KB+7, KB+14, 5.0*SC
        L,    KB+7, KB+8                         ! 上側直邊2
        LARC, KB+8, KB+9, KB+13, 10.0*SC        ! 上凹弧 r10
        L,    KB+9, KB+1                         ! 上側直邊1
        AL, LB+1, LB+2, LB+3, LB+4, LB+5, LB+6, LB+7, LB+8, LB+9, LB+10
        *get, AB, AREA, , NUM, MAX
        VEXT, AB, , , 0, 0, TH                  ! 沿 +z 拉伸 0.25mm
        KDELE, KB+11, KB+14, 1                   ! 刪弧圓心構造點
        CSYS, 0
    *enddo
*enddo

! ============================================================================
! [ADDED 階段②] 6 導柱：下層(0/120/240°@ZPLO) + 上層(60/180/300°@ZPHI)；每根一 volume
!   垂直實心圓柱 r2.5，沿磁極方位軸 r=20.5，底坐磁極板頂面、頂齊平 ZTOP=26.80。
!   WPROTA 繞 z 不改 z 軸 → CYLIND 仍垂直；WPOFFS,RPOST,0,0（旋轉後 = 徑向）。不 boolean。
! ============================================================================
*do, layer, 1, 2
    *if, layer, eq, 1, then
        ZBP = ZPLO
        A0  = 0
    *else
        ZBP = ZPHI
        A0  = 60
    *endif
    *do, pole, 1, 3
        ANG = A0 + (pole-1)*120
        WPLANE, 1,0,0,0
        WPCSYS, -1, 0           ! WP = global cartesian
        WPROTA, ANG             ! 繞 WP z 轉 ANG（z 軸不變）
        WPOFFS, RPOST, 0, 0     ! 沿旋轉後 +x（= 徑向）移到導柱軸線
        CYLIND, RP, , ZBP, ZTOP ! 垂直實心圓柱（WP z = 全域 +z），ZBP→ZTOP
        CSYS, 0
    *enddo
*enddo

! ============================================================================
! [ADDED 階段③] yoke：rounded-rect 外盤 − rounded-rect 中心 cutout − 6 導柱孔（VSBV）
!   忠實 r5 圓角（外盤 4 角 + cutout 4 角）；厚 5.5 @ z[20.80,26.30]；6 孔對齊導柱。
!   rounded-rect 面 = 8 邊界 KP + 4 圓角中心 KP → 4 直邊 L + 4 角弧 LARC(r5) → AL → VEXT。
! ============================================================================
CSYS, 0
*dim, YAX, , 2                  ! 半寬 X：外盤 29.9、cutout 15.5
YAX(1) = 29.9*SC $ YAX(2) = 15.5*SC
*dim, YAY, , 2                  ! 半寬 Y：外盤 26.9、cutout 10.25
YAY(1) = 26.9*SC $ YAY(2) = 10.25*SC
THY = ZYT - ZYB                 ! yoke 厚 5.5

*do, ir, 1, 2
    AX = YAX(ir)
    AY = YAY(ir)
    *get, KB, KP, , NUM, MAX
    ! 8 邊界 KP（CCW，z=ZYB）：右邊→上邊→左邊→下邊
    K, KB+1,  AX,        -(AY-YRR),  ZYB       ! 右邊下
    K, KB+2,  AX,         (AY-YRR),  ZYB       ! 右邊上
    K, KB+3,  (AX-YRR),   AY,        ZYB       ! 上邊右
    K, KB+4, -(AX-YRR),   AY,        ZYB       ! 上邊左
    K, KB+5, -AX,         (AY-YRR),  ZYB       ! 左邊上
    K, KB+6, -AX,        -(AY-YRR),  ZYB       ! 左邊下
    K, KB+7, -(AX-YRR),  -AY,        ZYB       ! 下邊左
    K, KB+8,  (AX-YRR),  -AY,        ZYB       ! 下邊右
    ! 4 圓角中心 KP
    K, KB+9,  (AX-YRR),   (AY-YRR),  ZYB       ! TR 中心
    K, KB+10,-(AX-YRR),   (AY-YRR),  ZYB       ! TL 中心
    K, KB+11,-(AX-YRR),  -(AY-YRR),  ZYB       ! BL 中心
    K, KB+12, (AX-YRR),  -(AY-YRR),  ZYB       ! BR 中心
    *get, LB, LINE, , NUM, MAX
    L,    KB+1, KB+2                            ! 右直邊
    LARC, KB+2, KB+3, KB+9,  YRR                ! TR 角弧
    L,    KB+3, KB+4                            ! 上直邊
    LARC, KB+4, KB+5, KB+10, YRR                ! TL 角弧
    L,    KB+5, KB+6                            ! 左直邊
    LARC, KB+6, KB+7, KB+11, YRR                ! BL 角弧
    L,    KB+7, KB+8                            ! 下直邊
    LARC, KB+8, KB+1, KB+12, YRR                ! BR 角弧
    AL, LB+1, LB+2, LB+3, LB+4, LB+5, LB+6, LB+7, LB+8
    *get, AB, AREA, , NUM, MAX
    VEXT, AB, , , 0, 0, THY                     ! 沿 +z 拉伸 5.5（z ZYB→ZYT）
    KDELE, KB+9, KB+12, 1                       ! 刪圓角中心構造點
    *if, ir, eq, 1, then
        *get, V_OUT, VOLU, , NUM, MAX          ! 外盤 volume 號（cutout+孔 = V_OUT+1..+7）
    *endif
*enddo

! 6 導柱孔 r2.5（對齊導柱位置 r20.5 @ 0/60/…/300°）
*do, ih, 1, 6
    HANG = (ih-1)*60
    HX = RPOST*cos(HANG)
    HY = RPOST*sin(HANG)
    WPLANE, 1,0,0,0
    WPCSYS, -1, 0
    WPOFFS, HX, HY, 0
    CYLIND, YHR, , ZYB, ZYT
    WPOFFS, -HX, -HY, 0
*enddo

! 一次 VSBV：外盤 − (cutout + 6 孔) → yoke 1 volume（沿用 PART C 避序號重用坑）
CSYS, 0
VSEL, S, VOLU, , V_OUT, V_OUT+7
VSBV, V_OUT, ALL
ALLSEL, ALL

! ============================================================================
! [ADDED 階段④ 2026-07-17] 6 襯套（sleeve/bushing）：凸緣頂帽狀空心襯套，套上 6 導柱
!   總組合.STEP 尺寸：bore r2.5、tube 外徑 r3.5、flange 外徑 r7.5；
!   flange 段 z[15.60,16.60]（厚1.0）、tube 段 z[16.60,20.80]（長4.2）、bore r2.5 貫穿。
!   6 個在 r=20.5 @ 0/60/…/300°、全垂直、同 z；每個 = (flange VADD tube) VSBV bore → 空心環
!   （導柱 r2.5 填內孔、不與襯套體積重疊）。WPROTA 繞 z 不改 z 軸 → CYLIND 仍垂直。
! ============================================================================
!   空心 CYLIND（外徑,內徑）直接建環，免挖孔；flange 環 + tube 環 VADD 成一頂帽。
!   ⚠ boolean 輸出取「最低可用號」非 max → 每個襯套後 NUMCMP,VOLU 壓實、下輪 *GET MAX 才對。
SLV_RF = 7.5*SC             ! flange 外徑
SLV_RT = 3.5*SC             ! tube 外徑
SLV_RB = 2.5*SC             ! bore 內徑（= 導柱 r2.5）
SLV_ZB = 15.60*SC           ! 襯套底（flange 底）
SLV_ZM = 16.60*SC           ! flange 頂 / tube 底
SLV_ZT = 20.80*SC           ! tube 頂（接 yoke 底）
NUMCMP, VOLU                ! 壓實至 1..13（yoke boolean 留下的號洞清掉）
*do, s, 1, 6
    ANG = (s-1)*60
    WPLANE, 1,0,0,0
    WPCSYS, -1, 0
    WPROTA, ANG             ! 繞 WP z 轉 ANG（z 軸不變）
    WPOFFS, RPOST, 0, 0     ! 沿旋轉後 +x（= 徑向）移到襯套/導柱軸線
    CYLIND, SLV_RF, SLV_RB, SLV_ZB, SLV_ZM   ! 空心 flange 環（外7.5 內2.5）
    *get, VF, VOLU, , NUM, MAX
    CYLIND, SLV_RT, SLV_RB, SLV_ZM, SLV_ZT   ! 空心 tube 環（外3.5 內2.5）
    *get, VT, VOLU, , NUM, MAX
    VADD, VF, VT                              ! flange 環 + tube 環 → 空心頂帽（1 volume）
    NUMCMP, VOLU                              ! 壓實，下一輪號碼連續
    CSYS, 0
*enddo
ALLSEL, ALL

NUMCMP, ALL
VPLOT

*get, NVOL, VOLU, , COUNT
/GO
*MSG, INFO, NVOL
FullAssembly volume count (expect 19 = 6 poles + 6 posts + 1 yoke + 6 sleeves) = %I
SAVE, 'full_assembly', 'db'
FINISH

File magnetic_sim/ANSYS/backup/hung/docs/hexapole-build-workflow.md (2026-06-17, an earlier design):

# Hexapole Pole Tip 建模流程

## 步驟 1：決定 tip 位置

### 請使用者提供以下資訊

> **問題 1：球體半徑 R 是多少 mm？**
>
> 這是每個 pole tip 到 working point（球心）的距離。
> 同一 pair 的 tip-to-tip 距離 = 2×R。
>
> 例如：R = 0.5 mm → tip-to-tip = 1.0 mm

> **問題 2：相鄰 pole 的間距角度是多少度？**
>
> 從俯視圖看，相鄰兩根 pole 之間的方位角間距。
> 標準 hexapole = 60°（6 根 pole 均勻分布 360°）。
>
> 例如：spacing = 60°

### 輸入參數總表

| # | 參數 | 說明 | 範例 |
|---|---|---|---|
| 1 | 球體半徑 R (mm) | 每個 tip 到 working point 的距離 | 0.5 |
| 2 | Pole 間距角度 (°) | 相鄰 pole 在俯視圖的方位角間距 | 60 |

### Pole 編號與排列（俯視圖，逆時針）

X+ 方向固定指向 P1。

```
              P5 (upper, 60°)
             /
P3 (lower, 120°)       P1 (lower, 0°) → X+
             \         /
              ● center
             /         \
P2 (upper, 180°)       P4 (upper, 300°)
             \
              P6 (lower, 240°)
```

| 方位角 | Pole | 層 | Pair |
|---|---|----|---|
| 0° | P1 | lower | I |
| 60° | P5 | upper | III |
| 120° | P3 | lower | II |
| 180° | P2 | upper | I |
| 240° | P6 | lower | III |
| 300° | P4 | upper | II |

對面 pole 相差 180°，同一 pair：P1↔P2、P3↔P4、P6↔P5。
上下層交替排列，每隔 60°。

### 座標系對齊

**ANSYS 座標系 = Measured 座標系**，不需要額外轉換：

| 軸 | ANSYS 方向 | Measured 方向 | 指向 |
|----|---|---|---|
| +X | +X | X_m | P1 (0°) |
| +Y | +Y | Y_m 投影 | P5 方向 (60°) |
| +Z | +Z | 垂直向上 | 上層 tip 側 |

SolidWorks 開 IGES 後看到的方向直接對應 measured 座標系：
- **+X 方向的 pole = P1**
- **右上 60° 方向 = P5**
- **左邊 180° = P2**

### 執行方式

使用者回答問題後，Claude 自動將值代入 MATLAB 程式碼中的 `[USER]` 變數並執行。

### 輸出

2 張 MATLAB 圖：

1. **3D 球面圖**（`step1_sphere_3D.png`）：6 個 tip 點在球面上的位置，標注 P1-P6 編號與 upper/lower
2. **俯視圖**（`step1_topview.png`）：X+ 指向 P1，標注編號、間距角度、upper/lower

### MATLAB 程式碼

```matlab
%% ===== Step 1: Pole Tip Positions =====
% ===== [USER] 使用者修改這兩行 =====
R = 0.5;          % [USER] 球體半徑 (mm)
spacing = 60;     % [USER] pole 間距角度 (°)

% Magic angle: cos^2(theta) = 1/3
theta_deg = acosd(1/sqrt(3));  % 54.74° (極角)
h = R*cosd(theta_deg);         % 上層平面高度
r = R*sind(theta_deg);         % 上層圓半徑

% Pole 定義 (X+ 指向 P1, 逆時針排列)
pole_names = {'P1','P5','P3','P2','P6','P4'};
pole_types = {'lower','upper','lower','upper','lower','upper'};
pole_az = [0, 60, 120, 180, 240, 300];

% Tip 座標
tips = zeros(6,3);
for i = 1:6
    phi = pole_az(i);
    if strcmp(pole_types{i},'upper')
        tips(i,:) = [r*cosd(phi), r*sind(phi), h];
    else
        tips(i,:) = [r*cosd(phi), r*sind(phi), -h];
    end
end
pair_idx = [1 4; 3 6; 5 2]; % P1↔P2, P3↔P4, P6↔P5

up_clr = [0 0.4 0.8]; lo_clr = [0.8 0.2 0.2];

%% 圖 1：3D 球面圖
fig1 = figure('Color','w','Position',[50 50 800 700]);
[xs,ys,zs] = sphere(40);
surf(xs*R, ys*R, zs*R, 'FaceAlpha',0.1, 'EdgeAlpha',0.06, 'FaceColor',[0.7 0.8 1]);
hold on; axis equal; grid on;
tt = linspace(0, 2*pi, 200);
plot3(r*cos(tt), r*sin(tt), h*ones(size(tt)), 'b--', 'LineWidth',1);
plot3(r*cos(tt), r*sin(tt), -h*ones(size(tt)), 'r--', 'LineWidth',1);
for i = 1:6
    if strcmp(pole_types{i},'upper')
        clr = up_clr; mk = 'v';
    else
        clr = lo_clr; mk = '^';
    end
    plot3(tips(i,1), tips(i,2), tips(i,3), mk, ...
        'MarkerSize',12, 'MarkerFaceColor',clr, 'Color',clr);
    text(tips(i,1)*1.5, tips(i,2)*1.5, tips(i,3)*1.2, ...
        sprintf('%s (%s)', pole_names{i}, pole_types{i}), ...
        'FontSize',11, 'FontWeight','bold', 'Color',clr, ...
        'HorizontalAlignment','center');
end
for k = 1:3
    i1 = pair_idx(k,1); i2 = pair_idx(k,2);
    plot3([tips(i1,1) tips(i2,1)], [tips(i1,2) tips(i2,2)], ...
        [tips(i1,3) tips(i2,3)], 'k--', 'LineWidth',1.2);
end
plot3(0,0,0, 'k+', 'MarkerSize',15, 'LineWidth',2.5);
xlabel('X (mm)'); ylabel('Y (mm)'); zlabel('Z (mm)');
title(sprintf('Step 1: Pole Tip Positions (R = %.1f mm)', R));
view(35, 25);
print(fig1, 'step1_sphere_3D.png', '-dpng', '-r200');

%% 圖 2：俯視圖 (Top View) — Measured 座標系
fig2 = figure('Color','w','Position',[50 50 1000 1000]);
hold on; axis equal; axis off;
tt = linspace(0, 2*pi, 200);
line_len = R*2.0;
for i = 1:6
    phi = pole_az(i);
    if strcmp(pole_types{i},'upper')
        clr = up_clr;
    else
        clr = lo_clr;
    end
    plot([0, line_len*cosd(phi)], [0, line_len*sind(phi)], '-', ...
        'Color', clr, 'LineWidth', 4);
    plot(tips(i,1), tips(i,2), 'o', 'MarkerSize', 10, ...
        'MarkerFaceColor', clr, 'Color', 'k', 'LineWidth', 1.5);
    text(R*2.7*cosd(phi), R*2.7*sind(phi), ...
        sprintf('%s\n(%s)', pole_names{i}, pole_types{i}), ...
        'FontSize', 14, 'FontWeight', 'bold', 'Color', clr, ...
        'HorizontalAlignment', 'center', 'VerticalAlignment', 'middle');
end
% Pair 虛線
for k = 1:3
    i1 = pair_idx(k,1); i2 = pair_idx(k,2);
    p1 = line_len*[cosd(pole_az(i1)), sind(pole_az(i1))];
    p2 = line_len*[cosd(pole_az(i2)), sind(pole_az(i2))];
    plot([p1(1) p2(1)], [p1(2) p2(2)], 'k--', 'LineWidth', 1);
end
% 間距弧線
arc_r = R*1.5;
for i = 1:6
    a1 = pole_az(i);
    if i < 6
        a2 = pole_az(i+1);
    else
        a2 = pole_az(1) + 360;
    end
    arc_a = linspace(a1, a2, 30);
    plot(arc_r*cosd(arc_a), arc_r*sind(arc_a), '-', 'Color', [0.5 0.5 0.5]);
    mid_a = (a1 + a2)/2;
    text(arc_r*1.12*cosd(mid_a), arc_r*1.12*sind(mid_a), ...
        sprintf('%d°', spacing), 'FontSize', 11, 'Color', [0.4 0.4 0.4], ...
        'HorizontalAlignment', 'center');
end
% Measured 座標系：X_m → P1 (0°), Y_m → P5 (60°)
ax_len = R*0.85;
red = [0.85 0 0];
plot([0 ax_len], [0 0], '-', 'Color', red, 'LineWidth', 2.5);
plot(ax_len, 0, '>', 'Color', red, 'MarkerFaceColor', red, 'MarkerSize', 8);
text(ax_len+0.05, -0.02, 'X_m', 'FontSize', 13, 'FontWeight', 'bold', 'Color', red);
plot([0 ax_len*cosd(60)], [0 ax_len*sind(60)], '-', 'Color', red, 'LineWidth', 2.5);
plot(ax_len*cosd(60), ax_len*sind(60), '^', 'Color', red, 'MarkerFaceColor', red, 'MarkerSize', 8);
text(ax_len*cosd(60)+0.04, ax_len*sind(60)+0.02, 'Y_m', ...
    'FontSize', 13, 'FontWeight', 'bold', 'Color', red);
plot(0, 0, 'k.', 'MarkerSize', 10);
% 圖例
lx0 = -R*2.8; ly0 = -R*2.5;
plot(lx0, ly0, 'o', 'MarkerSize', 8, 'MarkerFaceColor', up_clr, 'Color', 'k');
text(lx0+0.05, ly0, 'upper pole', 'FontSize', 12, 'Color', up_clr, ...
    'FontWeight', 'bold', 'VerticalAlignment', 'middle');
plot(lx0, ly0-0.12, 'o', 'MarkerSize', 8, 'MarkerFaceColor', lo_clr, 'Color', 'k');
text(lx0+0.05, ly0-0.12, 'lower pole', 'FontSize', 12, 'Color', lo_clr, ...
    'FontWeight', 'bold', 'VerticalAlignment', 'middle');
plot([lx0 lx0+0.06], [ly0-0.24 ly0-0.24], 'k--', 'LineWidth', 1);
text(lx0+0.08, ly0-0.24, 'pair connecting line', 'FontSize', 10, ...
    'Color', [0.3 0.3 0.3], 'VerticalAlignment', 'middle');
title(sprintf('Top View (Measured coord.): R = %.1f mm, spacing = %d°', R, spacing), 'FontSize', 14);
margin = R*3.2;
xlim([-margin margin]); ylim([-margin margin]);
print(fig2, 'step1_topview.png', '-dpng', '-r200');
```

---

## 步驟 2：擺放 pole 並建立 APDL 模型

### 請使用者提供以下資訊

> **問題：你的上層和下層 pole 要以什麼角度擺放？**
>
> 請參考下圖，回答兩個角度：

```
        Block (上, 外)
            \
             \  α_upper（上層傾斜角）
              \_________ 水平面
               \
                Tip (下, 內)          ← upper pole (P2, P4, P5)
                                       從 tip 沿軸往上、往外延伸到 block

                Tip (上, 內)          ← lower pole (P1, P3, P6)
               /  α_lower（下層傾斜角）
              /_________ 水平面
             /
        Block (下, 外)                 從 tip 沿軸往下、往外延伸到 block
```

| # | 參數 | 說明 | 範例 |
|---|---|---|---|
| 3 | α_upper (°) | 上層 pole 相對水平往上的傾斜角 | 35° |
| 4 | α_lower (°) | 下層 pole 相對水平往下的傾斜角 | 5.71° |

> **注意**：兩個角度都填正值。上層代表「往上幾度」，下層代表「往下幾度」。

### 執行方式

使用者回答問題後，Claude 自動將值代入 APDL 程式碼中的 `[USER]` 變數、執行 ANSYS、匯出 IGES。

### Pole 尺寸（from Mag_Pole_Bottom.STEP）

| 參數 | 值 | 說明 |
|---|-----|---|
| 圓柱半徑 | 3.175 mm | |
| 錐段長度 | 15.875 mm | semi-angle 11.31° |
| 總長 | 43 mm | |
| Tip | 尖錐頂點 | STEP 無 fillet |

### 輸出

- IGES 檔案 → SolidWorks 開啟量測驗證
- 使用者在 SolidWorks 量 tip-to-tip 距離，應為 2×R（例如 1.0 mm）

### APDL 注意事項

| # | 陷阱 | 解法 |
|---|---|---|
| 1 | 乘號 `*` 前後有空格 → APDL 當成註解 | `cos(theta)*R_sphere`（不留空格） |
| 2 | IGES 單位：ANSYS 寫 meters，SolidWorks 讀成 inches | 內部用 `MM = 1.0/25.4` 轉英寸 |
| 3 | Magic angle 搞混極角/仰角 | 極角 θ = acosd(1/√3) = 54.74° |
| 4 | VROTAT 接縫與削平面重合 | 截面偏移用 profile45 旋轉 45° |

### APDL 程式碼（已測試通過）

使用者需修改的參數標記為 `[USER]`。
含座標對齊（ANSYS +X = P1）、兩段式削平（前段 D 型 + 後段全圓）。

- **上層 pole**：削平面朝上
- **下層 pole**：削平面朝下（轉 180°）

完整腳本見 `magnetic_sim/ANSYS/backup/hung/apdl/variants/MT_Hung_SphereModel.txt`，以該檔案為準。

### 削平方法

不使用 VSBV（已知會失敗），改用**兩段式 VROTAT**：

| 段 | 範圍 | VROTAT | 結果 |
|----|---|---|---|
| 前段 | tip → 28mm | 180°, 2 divisions | D 型半圓（削平） |
| 後段 | 28mm → 43mm | 360°, 4 divisions | 全圓柱 |

削平面方向由截面偏移決定：
- Upper pole: `-side_perp` → 保留下半 → 削平面朝上
- Lower pole: `+side_perp` → 保留上半 → 削平面朝下

### SolidWorks 驗證清單（步驟 2）

- [ ] P1 在 +X 方向（SolidWorks 右邊）
- [ ] tip-to-tip 距離 = 2×R mm
- [ ] 俯視 60° 等距
- [ ] 前段 D 型、後段全圓柱
- [ ] 上層削平面朝上、下層朝下

---

## 步驟 3：安裝 Block

### 請使用者提供以下資訊

> **問題 5：上層 pole 伸入 block 多少 mm？（沿 pole 軸量）**
> 例如：7mm
>
> **問題 6：下層 pole 伸入 block 多少 mm？（沿 pole 軸量）**
> 例如：4.5mm

### 輸入參數

| # | 參數 | 說明 | 範例 |
|---|---|---|---|
| 5 | 上層伸入量 (mm) | pole 尾端沿軸進入 block 的深度 | 7 |
| 6 | 下層伸入量 (mm) | 同上 | 4.5 |

### 執行方式

使用者回答後，Claude 自動代入 APDL 並執行。

### Block 尺寸（from STEP）

| | Upper Block | Lower Block |
|--|---|---|
| 外形 | 25 × 22 × 10 mm | 22 × 22 × 10 mm |
| L 型截面 Part 1 | side -0.25~12.75, up ±11 | side 2~9, up ±11 |
| L 型截面 Part 2 | side -12.25~-0.25, up ±5 | side -13~2, up ±5 |
| STEP 來源 | `upper_block.STEP` | `lower_block.STEP` |
| Setting 參考 | `upper_block_setting.STEP` | `lower_block_setting.STEP` |

### 上下層安裝邏輯不同

```
Upper pole (35°傾斜):          Lower pole (5.71°傾斜):
pole 從 block 底面進入           pole 從 block 側面穿過

    ┌──────────┐ outer          ┌──────────┐
    │          │                │  ●═══════╪═ pole (幾乎水平)
    │  ● end   │                │  pole 在  │
    │  ╱       │                │  block    │
    │ ╱ 7mm    │                │  中央     │
    ├╱─────────┤ entry          └──────────┘
    ╱ pole

Block Z:                        Block Z:
  bottom = entry_z              center = pole_tail_z
  top = entry_z + 10mm          ±5mm (居中)

Block XY 中心:                  Block XY 中心:
  = pole 軸在 outer face         = pole 尾端 XY
```

### Block 建模方法

- **不使用 LOCAL CS**（已知會造成位置錯誤）
- 用 **global 座標算 8 角點 + V 指令**建每個 sub-block
- L 型截面 = 2 個矩形 VADD 合併
- 寬邊朝 workspace（XY 方向用 azimuth+180° 旋轉）

### APDL 注意事項（Block 專用）

| # | 陷阱 | 解法 |
|---|---|---|
| 1 | CSKP + LOCAL CS 建 BLOCK 位置會錯 | 用 global 座標 V 指令 |
| 2 | Upper/Lower 安裝邏輯不同 | Upper: 從底面進入; Lower: 從側面穿過，居中 |
| 3 | STEP 截面 slot 不在原點 | Upper 平移 +0.25mm, Lower 平移 -2mm |
| 4 | VADD 可能失敗（不影響幾何） | 45 volumes 正常（36 pole + 9 block） |

### SolidWorks 驗證清單（步驟 3）

- [ ] 6 個 block 都在 pole 尾端
- [ ] 上層 block：pole 從底面進入，pole 尾端在 block 內
- [ ] 下層 block：pole 從側面穿過，pole 在 block 垂直中央，不凸出
- [ ] Block 寬邊朝 workspace（朝 hexapole 中心方向）

---

## 步驟 4：安裝 Yoke（環形鐵板）

### 參數

| 參數 | 值 | 說明 |
|---|-----|---|
| YOKE_RI | 38.0 mm | 內徑（from 導磁鐵環.STEP） |
| YOKE_RO | 62.5 mm | 外徑（from 導磁鐵環.STEP） |
| YOKE_T | 2.0 mm | 厚度 |
| COIL_H | 14.0 mm | Block 頂到 Yoke 底的間距（coil 空間） |

### Z 位置鏈

```
fc_up_endz = fc_tz(P2) + POLE_TOTAL_LEN*sin(TILT_UP)     ! 上層 pole 尾端 Z
fc_up_blk_top = fc_up_endz + BLK_T/2                       ! 上層 block 頂
fc_yoke_zbot = fc_up_blk_top + COIL_H                      ! Yoke 底面
fc_yoke_ztop = fc_yoke_zbot + YOKE_T                       ! Yoke 頂面
```

### 建模方法

截面矩形 KP（R_inner, zbot）→（R_outer, zbot）→（R_outer, ztop）→（R_inner, ztop），加軸 KP 在 Z 軸上，VROTAT 360°, 4 divisions。

---

## 步驟 5：安裝 Guide Post（3 根）+ Upper Core（3 根）

### Guide Post（下層 P1, P3, P6）

| 參數 | 值 | 說明 |
|---|-----|---|
| GP_R | 4.0 mm | 半徑 |
| GP 頂端 Z | fc_yoke_zbot | 接 yoke 底面 |
| GP 底端 Z | fc_lo_endz - BLK_T/2 + 3.56 mm | lower block 底 + 3.56mm |
| GP XY | pole 尾端 XY | = fc_tx(i) + POLE_TOTAL_LEN*cos(TILT_DN)*cos(azim) |

建法：截面矩形 KP + VROTAT 360°, 4 divisions。3 根迴圈建立（P1, P3, P6）。

### Upper Core（上層 P2, P4, P5）

| 參數 | 值 | 說明 |
|---|-----|---|
| UC_R | 4.0 mm | 與 GP 相同 |
| UC 底端 Z | fc_up_blk_top2 = fc_up_endz + BLK_T/2 | upper block 頂面 |
| UC 頂端 Z | fc_yoke_zbot | 接 yoke 底面 |
| UC XY | pole 尾端 XY | = fc_tx(i) + POLE_TOTAL_LEN*cos(TILT_UP)*cos(azim) |

建法同 GP。3 根迴圈建立（P2, P4, P5）。

---

## 步驟 6：VADD + 空氣域 + VOVLAP + VGLUE

### 合併鋼件

```apdl
VADD, P51X    ! 所有 steel volumes → 1 個合併體
```

### 空氣域

| 域 | 幾何 | 參數 |
|----|---|---|
| 球形精細區 | SPHERE | R = 7.0 mm，原點 |
| 圓柱外空氣 | CYL4 | R = 80 mm, H = 80 mm，Z 中心在模型中點 |

### Boolean 操作

```apdl
VOVLAP, ALL         ! 重疊所有 volumes
NUMCMP, VOLU         ! 壓縮 volume 編號
VGLUE, 8, 1,2,3,4,5,6  ! Glue 鋼件(V8)與 tips(V1-6)
```

### 結果：9 Volumes

| Volume | 內容 | 材料 |
|---|---|---|
| V1-V6 | 6 根 pole tip（球內鐵） | MAT 2 (μr=280) |
| V7 | 球內空氣 | MAT 1 (μr=1) |
| V8 | 鋼主體（yoke + GP + cores + blocks + pole 外段） | MAT 2 (μr=280) |
| V9 | 圓柱外空氣 | MAT 3 (μr=1) |

---

## 步驟 7：材料 + Mesh + SOURC36 + 求解

### 材料與元素

```apdl
ET, 1, SOLID96       ! 磁純量勢元素
ET, 2, SOURC36       ! 電流源元素
MP, MURX, 1, 1       ! V7: 球內空氣
MP, MURX, 2, 280     ! V1-6, V8: 1018 鋼
MP, MURX, 3, 1       ! V9: 外空氣
```

### 分區 Mesh

| 區域 | Volumes | ESIZE | 說明 |
|---|---|---|---|
| Pole tips | V1-V6 | 0.3 mm | 最細（尖端需高解析） |
| 球內空氣 | V7 | 0.3 mm | 細（WP 區域） |
| 鋼主體 | V8 | 1.5 mm | 中等 |
| 外空氣 | V9 | 4.0 mm | 粗 |

目標：~2-3M elements。

### SOURC36 Coil 定義

| 參數 | 值 | 說明 |
|---|-----|---|
| TURNS | 70 | 匝數 |
| COIL_MEAN_R | 11.0 mm | (R_in=10 + R_out=12) / 2 |
| COIL_DY | 2.0 mm | R_out - R_in = 12 - 10 |
| COIL_DZ | 15.0 mm | 高度 |
| Coil 位置 Z | block_top + COIL_DZ/2 | 貼在 block 正上方 |
| Coil XY | pole 尾端 XY | 跟 GP/UC 相同 |
| 繞向 | 順時針（N1/N2 swap） | flux 向 -Z（toward block） |

Real constants：`R, i, 1, TURNS*CURR_ARRAY(i), COIL_DY, COIL_DZ`

CURR_ARRAY：每個檔案只激發 1 個 coil（coilN 檔 → CURR_ARRAY(N)=1，其餘=0）。

### 邊界條件

```apdl
! 圓柱頂面 MAG=0
NSEL, S, LOC, Z, z_top ± 1e-5
D, ALL, MAG, 0
! 圓柱底面 MAG=0
NSEL, S, LOC, Z, z_bot ± 1e-5
D, ALL, MAG, 0
! 圓柱側面 MAG=0 (用 LOCAL cylindrical CS)
LOCAL, 99, 1, 0, 0, 0
NSEL, S, LOC, X, AIR_CYL_R*0.99, AIR_CYL_R*1.01
D, ALL, MAG, 0
```

### 求解

```apdl
magsolv, 3, , , , , 1    ! DSP 方法
```

### SolidWorks 驗證清單（步驟 7 前）

- [ ] 9 volumes 正確（V1-6 tips, V7 sphere air, V8 steel, V9 cyl air）
- [ ] 材料指定正確（VATT）
- [ ] Mesh 完成無 error
- [ ] SOURC36 nodes 在正確位置（block 上方）
- [ ] MAG=0 BC 在外表面

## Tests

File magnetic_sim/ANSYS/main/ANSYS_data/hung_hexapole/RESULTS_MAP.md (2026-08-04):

# hung_hexapole — RESULTS_MAP（讀 FEM 結果前必查，凌駕 memory）

依 `.claude/rules/result-read-safety.md`：讀任何 hung_hexapole 結果前，先在此核路徑 + 指紋。

**路徑格式**：`data/<variant>/coil<N>/`（2026-07-14 起，`data/coil<N>/<variant>/` 舊式已淘汰）。
讀取碼一律 `import_ansys_data(fullfile(root,<variant>,'coil<N>'), <dataset>, 'coil<N>')`。

## 模型
hung_hexapole 6 極 electromagnetic microprobe，**native APDL primitive 重建**（非 CAD 匯入；匯入不能布林）。
WP 在原點（`SPH_OFST = 0`）。詳見 memory `[[hung-hexapole-primitive-sim]]`。

- **coil 編號 = identity**：mesh deck `fc_ra(1..6) = 0/180/120/300/60/240°` + `REAL,fc_pi` → real set k = 論文 P k。
- **號誌**：deck `R,N,1,TURNS*1`（正號）→ raw 六極**全 sink** → config `s_source = [-1×6]` 全域翻號成 source。
- 電流 = 1A（FEM 激發）；下游 fit 的 I 必須 = 1（`.claude/rules/fit-current-matches-sim.md`）。
- 單位：公尺 MKS，B 輸出 Tesla。

---

## ✅ 可用結果：R 家族（原始設計 + 兩個 R_sphere 變體）

三變體**同一支純版 deck**（`MT_Mesh_Graded.txt`）只改 `R_sphere`；`R500` = 原始設計值、
= `config/hung_hexapole/mt_constants.m` 的 `R_norm = 500e-6`，**現為 `default_variant`**。

| variant | R_sphere（tip→WP） | mesh 節點 / 元素 | `.dat` bfield_all 行數 | wp matched 節點 |
|---|---|---|---|---|
| `R300` | 0.3 mm | 589,264 / 3,520,338 | 589,248 | 439,015 |
| **`R500`**（default）| **0.5 mm** | **560,277 / 3,349,759** | **560,261** | **402,771** |
| `R700` | 0.7 mm | 791,452 / 4,745,571 | 791,436 | 622,074 |

⚠ **節點數對 R 非單調**（R300 > R500）：graded `EREFINE` 是 band-based，R 縮小時極尖端擠進內層細網格球
反而觸發更多細化。別拿「幾何變大→節點變多」當驗收判準。

### 指紋：WP 中心（最近節點，r_min ≈ 0.6–1.2 µm）1A 激發

| variant | 下極 P1 / P3 / P6 \|B\| | 下極 Bz | 上極 P2 / P4 / P5 \|B\| | 上極 Bz | \|B\|_max（wp 集） |
|---|---|---|---|---|---|
| `R300` | 16.58 / 16.70 / 16.61 mT | −9.1 mT | 15.75 / 15.56 / 15.59 mT | +8.4 mT | 1.31–1.41 T |
| **`R500`** | **9.72 / 9.73 / 9.79 mT** | **−5.33 mT** | **9.24 / 9.16 / 9.17 mT** | **+4.93 mT** | 1.19–1.27 T |
| `R700` | 6.96 / 6.95 / 6.96 mT | −3.81 mT | 6.58 / 6.52 / 6.53 mT | +3.53 mT | 1.13–1.22 T |

**對稱性判準**：同層三顆 \|B\| 散佈 < 1%；下極 Bz < 0、上極 Bz > 0；下極略強於上極（+5~6%）。
任一條不符 → 停下來查是否讀錯 variant。

### 校正結果（single / USE_BIAS=false、R_select=150 µm）
`R500`：ℓ̂ = 887.7 µm、ᴮĝ_I = 9.2948 mT/A、RMSPE 2.58%、𝒞 = 2481、κ = 0.8652，K̄_I 四項判準全過。
PDF：`…/Calibration_using_FEM_modeling/results/hung_hexapole/single/model_results_current_R500.pdf`。

### 網格 / 解 db
| 路徑 | 內容 |
|---|---|
| `db/mesh/mesh_graded_R{300,500,700}/mesh_graded.db` | canonical 網格（SMRTSIZE5 + 二級 EREFINE：step1 全極 cone、step2 下極）+ 6 SOURC36 線圈（N70, r[4,7] 繞導柱） |
| `db/sim/R{300,500,700}/sim_coil<N>.{db,rmg}` + `magsolv.out` | 逐極解（half-clean 後：主 `.db` + 主 `.rmg` + 主 log） |
| `db/geom/geom_full_R{300,700}/` | 幾何 db + IGES（**非結果**，無 `.dat`） |
| `db/geom/from_parasolid/hung_hexapole_full.db` | CAD 匯入真實幾何（97 vol，**非 primitive、非 mesh**，參考用） |

---

## ⛔ 不可用：`gap_200um` / `no_gap`（**兩層原因，別再誤用**）

**① 六顆 coil 網格不一致 → 管線直接 crash**
`extract_ansys_data.m` 以 coil1 的 N 開 `B = zeros(N,3,6)` 再塞其餘 coil：

| variant | 各 coil matched 節點 |
|---|---|
| `no_gap` | coil1/3/6 = 655,901（Jul 10, `mesh_graded.db`）；**coil2/4/5 = 853,500（Jul 8 `meshbg.db` 的 stale data，從未在現行網格重解）** |
| `gap_200um` | **三套網格混雜**：589,276 / 655,931 / 853,530 |

**② `no_gap` 根本不是原始設計幾何**
建在 `MT_Mesh_Graded_BaseGap.txt`（自述 `[ADDED 2026-07-09 EXPERIMENT]`、註解明寫「非 CAD baseline」），
與純版 `MT_Mesh_Graded.txt` 差 102 行：有 200 µm base slab、**下極鐵棒縮短 43→38 mm**（`ROD_LEN_LO`）、
`GLOW_R=40`、`GAP_HW_LO=5`。⚠ 舊表把 655,919 節點的 BaseGap 網格當 canonical，**已作廢**。

> 舊 `gap_200um` 表述（μ_eff 支撐座：下極 μ=52.02 / 上極 μ=59.364，WP \|B\| 下 5.9 / 上 7.5 mT）
> 僅供辨識舊資料，**不得用於新分析**；如何處置（保留 / 刪除）另案。

---

## 讀取注意
- **預設讀 `R500`**（config `default_variant`）；要 R300/R700 必在 `main.m` 明設 `VARIANT`。
- ⚠ **config 的 `R_norm` 固定 500 µm、不隨 variant 變**：`R_act`（單位向量）與 `Pc_base`（無因次）不受影響，
  但 `filter_iron_nodes` 的錐體頂點與 `build_V_matrix` 的 sensor 位置用的是絕對座標。
  R≤150 µm 取樣球碰不到鐵，故 current-base 的 R300/R700 結果不受影響；**要做 voltage 或加大 R_select 前必須先處理**。
- dataset：`*_all.dat`（全節點）/ `*_wp.dat`（WP 球區，含匯聚細網格）。
- source 慣例見 `.claude/rules/charge-model-source-convention.md`（hung = 全 sink → 全域翻號）。

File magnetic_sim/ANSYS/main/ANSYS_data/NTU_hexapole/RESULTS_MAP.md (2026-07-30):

# RESULTS_MAP — NTU_hexapole

**Single source of truth：這個 topic 底下每個 result dir 是什麼、能不能信、載入後該看到什麼指紋。**

讀任何結果前**先查這張表**（規則：`.claude/rules/result-read-safety.md`）。本表凌駕 memory。
建立：2026-07-22（NTU `.dat` 前綴正規化成 `coilN` 之後）。

> **⚠ 2026-07-22 檔名正規化**：NTU 的 `.dat` 前綴由「類別名」改成 **`coilN`**，與 long2016/hung 一致。
> 例：`data/full_assembly/coil1/full_assembly_coord_all.dat` → `.../coil1_coord_all.dat`。
> 讀取碼一律 `import_ansys_data(fullfile(root,<variant>,'coil<N>'), <dataset>, 'coil<N>')`
> （第 3 引數＝`coilN`，**不再是類別名**）。所有 NTU 分析腳本已同步更新（13 處）。

---

## 結構

`data/<variant>/coil<N>/coil<N>_{coord,bfield}_<dataset>.dat`
- **variant**（= 幾何/組裝案例）：`full_assembly`（6 極全組裝，主力）、`full_assembly_sleeve`（加 6 襯套）、
  `singlepole`（單極板，只 coil1）、`upper_assembly`（上層組裝，只 coil1）。
- **dataset**：NTU 只有 `all`（無 `wp`）；`singlepole`/`upper_assembly` 另有 `sensor_S1`/`sensor_S2`（板下/板上 sensor 加密球）。
- NTU 為**扁平板幾何、WP 在原點附近**（WP 形心 ≈ [0,0,9.3] mm）；WP 附近取樣靠 MATLAB 端 `R_load`（2mm 球）預篩，
  不靠 `_wp` 檔。載入策略 = `ntu_flat`（不旋轉、不濾鐵），見 `matlab/APDL/Calibration_using_FEM_modeling/`。

---

## CANONICAL

| variant | coils | dataset | matched 節點（coil1） | WP 球 \|B\| 指紋（coil1，2mm 球內 max） |
|---|---|---|---|---|
| `full_assembly` | coil1–6（**六 coil 節點一致** 1787195） | all | **1787195** | **~839 mT** |
| `full_assembly_sleeve` | coil1–6 | all | ~1806621（coord 1806639） | （μr=1 襯套 ≡ 空氣 ≡ full_assembly，物理等價） |
| `singlepole` | coil1 | all + sensor_S1/S2 | ~279238（coord 279256） | sensor 球：S1 1433 / S2 1431 節點 |
| `upper_assembly` | coil1 | all + sensor_S1/S2 | ~710335（coord 710353） | sensor 球：S1 1433 / S2 1431 節點 |

- **map**：NTU `apdl_to_paper_idx = [1,3,6,5,2,4]`（同 long2016，deck 下極先/上極後）。
- **號誌**：NTU deck 電流反向 → raw FEM 全 source（不需翻號）；載入 `-1e3`（T→mT）。
- 驗證（2026-07-22）：共用 extractor（`ntu_flat`）對 `full_assembly` 載出 N=34543（2mm 球）、
  與 NTU per-model `load_coils_actuator` 逐值相同（diff=0）。

---

## 怎麼用（層②核指紋）

`import_ansys_data(<dir>, <dataset>, 'coil<N>')` 讀 `<dir>/coil<N>_coord_<dataset>.dat` +
`coil<N>_bfield_<dataset>.dat`，印 `Matched %d nodes`。載入後對照上表 matched 節點數；
`full_assembly` vs `full_assembly_sleeve` 節點數不同可直接分辨。

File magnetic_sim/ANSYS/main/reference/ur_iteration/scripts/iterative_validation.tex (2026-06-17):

\documentclass[border=10pt]{standalone}

\usepackage{tikz}
\usetikzlibrary{shapes.geometric, arrows.meta, positioning}
\usepackage{xeCJK}
\setCJKmainfont{Noto Sans CJK TC}

\tikzset{
    startstop/.style={
        rectangle, rounded corners,
        minimum width=3.5cm, minimum height=0.9cm,
        text centered, draw=black, fill=blue!10,
        font=\small
    },
    process/.style={
        rectangle,
        minimum width=4.5cm, minimum height=0.9cm,
        text centered, draw=black, fill=orange!15,
        font=\small
    },
    decision/.style={
        diamond, aspect=2.2,
        minimum width=4cm, minimum height=1cm,
        text centered, draw=black, fill=yellow!20,
        font=\small, inner sep=0pt
    },
    success/.style={
        rectangle, rounded corners,
        minimum width=4cm, minimum height=0.9cm,
        text centered, draw=black, fill=green!20,
        font=\small
    },
    arrow/.style={thick, -{Stealth[length=2.5mm]}}
}

\begin{document}

\begin{tikzpicture}[node distance=1.3cm]

\node (start) [startstop] {1. 初始猜 $\mu_r = 280$};

\node (sim) [process, below=of start] {2. 跑模擬,得到 $H$ 範圍 $[H_{\min},\,H_{\max}]$};

\node (lookup) [process, below=of sim] {3. 查表:該範圍內真實 $\mu_r$ 平均值 $=\mu_{r,\text{new}}$};

\node (check) [decision, below=1.5cm of lookup] {4. $\left|\mu_{r,\text{new}} - 280\right| < 10\%$?};

\node (yes) [success, below=1.6cm of check] {✅ 收斂,假設成立};

\node (no) [process, right=2.5cm of check] {改用 $\mu_{r,\text{new}}$ 重跑};

\draw [arrow] (start) -- (sim);
\draw [arrow] (sim) -- (lookup);
\draw [arrow] (lookup) -- (check);
\draw [arrow] (check) -- node[anchor=east, font=\small] {Yes} (yes);
\draw [arrow] (check) -- node[anchor=south, font=\small] {No} (no);
\draw [arrow] (no.north) |- ([yshift=2mm]sim.east) -- (sim.east);

\end{tikzpicture}

\end{document}

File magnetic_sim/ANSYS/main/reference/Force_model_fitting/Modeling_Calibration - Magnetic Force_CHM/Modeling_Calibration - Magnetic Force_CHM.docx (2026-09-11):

Magnetic Force Generation via Hexapole Electromagnetic Actuators: Hall-Sensor-Based Modeling and Calibration Approach:

Magnetic Force Generation:

m(p)=(3V)/(μ_o)((μ-μ_o)/(μ+2μ_o))Mg_B b(p)

f(p)=1/2∇(m∙B)=(3V)/(2μ_o)((μ-μ_o)/(μ+2μ_o))∇(B∙B)

Position-dependent 6×6×3 dimensionless spatial-distribution tensor L(p) :

p=p/l

{r_n =p-p_(c_n) , ;, r_n =‖r_n ‖ r_m =p-p_(c_m) , ;, r_m =‖r_m ‖

∇((r_n ∙r_m)/(r_n^3 r_m^3))=1/(r_n^3 r_m^3)[(1-(3(r_n ∙r_m ))/(r_n^2))r_n +(1-(3(r_n ∙r_m ))/(r_m^2))r_m ]=1/(l^5)1/(r_n^3 r_m^3)[(1-(3(r_n ∙r_m ))/(r_n^2))r_n +(1-(3(r_n ∙r_m ))/(r_m^2))r_m ]L(p; n,m,⋮)=l_(n,m) (p)

L(p/l,e) is the position-dependent 6×6×3 dimensionless spaitial-distribution tensor with 18 unknown parameters, i.e., l is an unknown constant and e is an unknown 17×1 vector. Let L_k represent the k-th symmetric 6×6 slice of the tensor L for k∈{1,2,3} ,

L(p; n,m,k)=[L_x (p; n,m)L_y (p; n,m)L_z (p; n,m)]=[L_1 (p; n,m)L_2 (p; n,m)L_3 (p; n,m)]=[L_k (p; n,m)k∈{1,2,3}] .

Current-based model:

f_k =((Mg_B)/(2l))(Bg_I )^2 I^T K^T L_k (p/l,e)KI

Calibration Approach:

1. Select N_p points in the work space.

p_i is the 3×1 position vector for for i=1,2,⋯,N_p .

I_j is the 6×1 input current vector for for j=1,2,⋯,N_I .

v_j is the 6×1 Hall sensor voltage vector for for j=1,2,⋯,N_v , wherein N_v =N_I .

f_(ij) =f_j (p_i ) is the 3×1 resulting force vector for for i=1,2,⋯,N_p and for j=1,2,⋯,N_I .

f_(ijk) =((Mg_B)/(2l))(Bg_I )^2 (I_j^T K^T )L_k ((p_i)/l,e)(KI_j ) for i=1,2,⋯,N_p and for j=1,2,⋯,N_I ,

wherein Mg_B is the theoretical magetization constant associated with the particle, and l , e , Bg_I , K , are previously obtained flux generation model parameters by calibration.

Voltage-based model:

f_k =Fg_V v^T M^T L_k (p/l,e)Mv=(v_j^T FH_V^T )L_k ((p_i)/l,e)(FH_V v_j )

2. Cost function (Scenario one):

The k-th element of the vector ε_(ij) is:

f_(ijk) =((Mg_B)/(2l))(Bg_I )^2 (I_j^T K^T )L_k ((p_i)/l,e)(KI_j ) (measurement)

ε_(ijk) (l,e, FH_V )=f_(ijk) -(v_j^T FH_V^T )L_k ((p_i)/l,e)(FH_V v_j )

ε_(ij)^T ε_(ij) (l,e, FH_V )=∑_(k=1)^3 (f_(ijk) -(v_j^T FH_V^T )L_k ((p_i)/l,e)(FH_V v_j ))^2

J(l,e, FH_V )=∑_(j=1)^(N_I) ∑_(i=1)^(N_p) ε_(ij)^T ε_(ij) =∑_(j=1)^(N_I) ∑_(i=1)^(N_p) ∑_(k=1)^3 (f_(ijk) -(v_j^T FH_V^T )L_k ((p_i)/l,e)(FH_V v_j ))^2

(∂J)/(∂FH_V)=-4∑_(j=1)^(N_I) ∑_(i=1)^(N_p) ∑_(k=1)^3 (f_(ijk) -(v_j^T FH_V^T )L_k ((p_i)/l,e)(FH_V v_j ))L_k ((p_i)/l,e)FH_V v_j v_j^T

Let (∂J)/(∂FH_V)=0 , can FH_V be expressed explicitly in terms of f_(ijk) , L_k , and v_j ?

No, FH_V cannot be expressed explicitly in closed form.

3. Minimize cost function:

Minimize J(l,e, FH_V )⟹l, e, FH_V (Initial guess: l=l_(design) , e=0 , and FH_V =√((Mg_B)/((2∙l_(design) )))Bg_I I_(6×6) ) ⟹Fg_V =(6/5h_11 )^2 and M=5/(6∙h_11)FH_V

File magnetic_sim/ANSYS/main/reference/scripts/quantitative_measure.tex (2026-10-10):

% Quantitative measure of the force model
% Compile: xelatex quantitative_measure.tex  -> ../Force_model/Quantitative measure/quantitative_measure.pdf
\documentclass[11pt]{article}
\usepackage[a4paper,margin=2.5cm]{geometry}
\usepackage{amsmath,amssymb}
\usepackage{xeCJK}
\usepackage{tikz}
\usetikzlibrary{arrows.meta}
\setCJKmainfont[AutoFakeBold=2.5]{DFKai-SB}   % 標楷體
\setlength{\parindent}{0pt}

% Typography: vectors and matrices upright bold (\mathbf), scalars italic, not bold.
% Norms are written without the subscript 2.
\newcommand{\rh}{\hat{\mathbf{r}}}
\newcommand{\xa}{\hat{\mathbf{x}}_a}
\newcommand{\ya}{\hat{\mathbf{y}}_a}
\newcommand{\za}{\hat{\mathbf{z}}_a}
\newcommand{\Ij}{\mathbf{I}_j}
\newcommand{\Ijh}{\hat{\mathbf{I}}_j}
\newcommand{\fij}{\mathbf{f}_{ij}}

\begin{document}

\begin{center}
{\LARGE\bfseries Quantitative measure of the force model}
\end{center}
\vspace{6pt}

% ---------------------------------------------------------------------------------------
\section*{步驟 1}

\subsection*{1.1\ \ 單位方向 $\rh(\theta,\varphi)$}

以致動座標系的基底 $\{\xa,\ \ya,\ \za\}$ 描述任意單位方向 $\rh$：

\begin{minipage}[c]{0.54\textwidth}
\[
\rh(\theta,\varphi)
=\cos\varphi\cos\theta\,\xa+\cos\varphi\sin\theta\,\ya+\sin\varphi\,\za
=\begin{bmatrix}
\cos\varphi\cos\theta\\
\cos\varphi\sin\theta\\
\sin\varphi
\end{bmatrix}
\]
\[
\left\{
\begin{aligned}
\varphi &\in [-90^\circ,\ 90^\circ] &&\text{仰角（自 $x_a$--$y_a$ 平面起算）}\\
\theta  &\in [0^\circ,\ 360^\circ)  &&\text{方位角（自 $+x_a$ 軸起算，繞 $z_a$）}
\end{aligned}\right.
\]
\[
\|\rh\|=1
\]
\end{minipage}
\hfill
\begin{minipage}[c]{0.42\textwidth}
\centering
\begin{tikzpicture}[scale=0.95,>={Latex[length=2.2mm]}]
  \coordinate (O) at (0,0);
  \draw[->,thick] (O) -- (0,2.7)        node[above]{$z_a$};
  \draw[->,thick] (O) -- (3.0,0)        node[right]{$y_a$};
  \draw[->,thick] (O) -- (-1.75,-1.45)  node[below left]{$x_a$};
  \coordinate (V) at (2.05,1.75);
  \coordinate (Q) at (1.55,-0.30);
  \draw[->,very thick] (O) -- (V) node[above right]{$\rh$};
  \draw[dashed] (O) -- (Q);
  \draw[dashed] (Q) -- (V);
  \draw[->] (0.95,-0.18) arc (-10.5:40.5:0.97);
  \node at (1.28,0.52) {$\varphi$};
  \draw[->] (-0.62,-0.52) arc (219.5:349.5:0.81);
  \node at (0.10,-0.95) {$\theta$};
\end{tikzpicture}
\end{minipage}

\subsection*{1.2\ \ 電流 $\Ij$}

位置 $\mathbf{p}_i$、第 $j$ 組電流 $\Ij$ 產生的力向量
\[
\fij=\begin{bmatrix} f_{ij1}\\ f_{ij2}\\ f_{ij3} \end{bmatrix},\qquad
f_{ijk}=\Ij^{\mathsf T}\,{}^{F}\hat{\mathbf{H}}_{I}^{\mathsf T}\,
\mathbf{L}_k\!\left(\mathbf{p}_i/\hat{\ell},\,\hat{\mathbf{e}}\right)\,{}^{F}\hat{\mathbf{H}}_{I}\,\Ij,
\qquad k=1,2,3
\]
令
\[
\Ij=\sqrt{\|\fij\|}\;\Ijh,\qquad
\fij\!\left(\mathbf{p}_i,\Ij\right)=\|\fij\|\,\rh
\]
代入力模型：
\[
\begin{aligned}
\fij
&=\begin{bmatrix}
\left(\sqrt{\|\fij\|}\,\Ijh\right)^{\!\mathsf T}{}^{F}\hat{\mathbf{H}}_{I}^{\mathsf T}\,\mathbf{L}_1\!\left(\mathbf{p}_i/\hat{\ell},\hat{\mathbf{e}}\right){}^{F}\hat{\mathbf{H}}_{I}\left(\sqrt{\|\fij\|}\,\Ijh\right)\\[2pt]
\left(\sqrt{\|\fij\|}\,\Ijh\right)^{\!\mathsf T}{}^{F}\hat{\mathbf{H}}_{I}^{\mathsf T}\,\mathbf{L}_2\!\left(\mathbf{p}_i/\hat{\ell},\hat{\mathbf{e}}\right){}^{F}\hat{\mathbf{H}}_{I}\left(\sqrt{\|\fij\|}\,\Ijh\right)\\[2pt]
\left(\sqrt{\|\fij\|}\,\Ijh\right)^{\!\mathsf T}{}^{F}\hat{\mathbf{H}}_{I}^{\mathsf T}\,\mathbf{L}_3\!\left(\mathbf{p}_i/\hat{\ell},\hat{\mathbf{e}}\right){}^{F}\hat{\mathbf{H}}_{I}\left(\sqrt{\|\fij\|}\,\Ijh\right)
\end{bmatrix}\\[6pt]
&=\|\fij\|
\begin{bmatrix}
\Ijh^{\mathsf T}\,{}^{F}\hat{\mathbf{H}}_{I}^{\mathsf T}\,\mathbf{L}_1\!\left(\mathbf{p}_i/\hat{\ell},\hat{\mathbf{e}}\right){}^{F}\hat{\mathbf{H}}_{I}\,\Ijh\\[2pt]
\Ijh^{\mathsf T}\,{}^{F}\hat{\mathbf{H}}_{I}^{\mathsf T}\,\mathbf{L}_2\!\left(\mathbf{p}_i/\hat{\ell},\hat{\mathbf{e}}\right){}^{F}\hat{\mathbf{H}}_{I}\,\Ijh\\[2pt]
\Ijh^{\mathsf T}\,{}^{F}\hat{\mathbf{H}}_{I}^{\mathsf T}\,\mathbf{L}_3\!\left(\mathbf{p}_i/\hat{\ell},\hat{\mathbf{e}}\right){}^{F}\hat{\mathbf{H}}_{I}\,\Ijh
\end{bmatrix}\\[6pt]
&=\|\fij\|\;\hat{\mathbf{f}}_{ij}\!\left(\mathbf{p}_i,\Ijh\right)
\end{aligned}
\]
比較得
\[
\hat{\mathbf{f}}_{ij}\!\left(\mathbf{p}_i,\Ijh\right)=\rh
\]
$\hat{\mathbf{f}}_{ij}(\mathbf{p}_i,\Ijh)$ 稱為單位力量，所對應的電流 $\Ijh$ 稱為單位電流。

% ---------------------------------------------------------------------------------------
\section*{步驟 2}

期望力 $\mathbf{f}_d$ 拆成大小與方向：
\[
\mathbf{f}_d=\|\mathbf{f}_d\|\,\rh(\theta,\varphi)
\]
\[
\mathbf{I}_{\mathrm{opt}}=\arg\min_{\Ij}\ \|\Ij\|^2
\qquad\text{s.t.}\quad \fij\!\left(\mathbf{p}_i,\Ij\right)=\mathbf{f}_d
\]
以 $\Ij=\sqrt{\|\fij\|}\;\Ijh$ 替換 $\Ij$：
\[
\|\Ij\|^2=\|\fij\|\,\|\Ijh\|^2,\qquad
\fij\!\left(\mathbf{p}_i,\Ij\right)=\|\fij\|\,\hat{\mathbf{f}}_{ij}\!\left(\mathbf{p}_i,\Ijh\right)=\mathbf{f}_d
\]
限制式給出 $\|\fij\|=\|\mathbf{f}_d\|$、$\hat{\mathbf{f}}_{ij}(\mathbf{p}_i,\Ijh)=\mathbf{f}_d/\|\mathbf{f}_d\|=\rh$，$\|\mathbf{f}_d\|$ 為常數。\\[4pt]
換成最小範數單位電流問題：
\[
\hat{\mathbf{I}}_{\mathrm{opt}}(\varphi,\theta,\mathbf{p}_i)=\arg\min_{\Ijh}\ \|\Ijh\|^2
\qquad\text{s.t.}\quad \hat{\mathbf{f}}_{ij}\!\left(\mathbf{p}_i,\Ijh\right)=\rh
\]
原問題的解：
\[
\mathbf{I}_{\mathrm{opt}}=\sqrt{\|\mathbf{f}_d\|}\;\hat{\mathbf{I}}_{\mathrm{opt}}(\varphi,\theta,\mathbf{p}_i)
\]

% ---------------------------------------------------------------------------------------
\section*{步驟 3}

固定位置 $\mathbf{p}_i$，以 Lagrange multipliers 求解任意方向 $\rh$ 的 $\hat{\mathbf{I}}_{\mathrm{opt}}(\varphi,\theta,\mathbf{p}_i)$。令
\[
\mathbf{Q}_k={}^{F}\hat{\mathbf{H}}_{I}^{\mathsf T}\,\mathbf{L}_k\!\left(\mathbf{p}_i/\hat{\ell},\hat{\mathbf{e}}\right){}^{F}\hat{\mathbf{H}}_{I},
\qquad k=1,2,3
\]
限制式 $\hat{\mathbf{f}}_{ij}(\mathbf{p}_i,\Ijh)=\rh$ 的第 $k$ 個分量為 $\Ijh^{\mathsf T}\mathbf{Q}_k\Ijh=r_k$，
Lagrange multipliers $\boldsymbol{\lambda}=\begin{bmatrix}\lambda_1 & \lambda_2 & \lambda_3\end{bmatrix}^{\mathsf T}$：
\[
\mathcal{L}\!\left(\Ijh,\boldsymbol{\lambda}\right)
=\|\Ijh\|^2-\sum_{k=1}^{3}\lambda_k\left(\Ijh^{\mathsf T}\mathbf{Q}_k\Ijh-r_k\right)
\]

% ---------------------------------------------------------------------------------------
\section*{步驟 4}

限制電流大小 $\|\Ij\|\le\|\mathbf{I}\|_{\max}$。由 $\Ij=\sqrt{\|\fij\|}\;\Ijh$：
\[
\|\Ij\|^2=\|\fij\|\,\|\Ijh\|^2
\quad\Longrightarrow\quad
\|\fij\|=\frac{\|\Ij\|^2}{\|\Ijh\|^2}
\]
代回 $\fij=\|\fij\|\,\rh$：
\[
\fij=\frac{\|\Ij\|^2}{\|\Ijh\|^2}\,\rh
\]
方向 $\rh$ 固定時，取 $\|\Ij\|=\|\mathbf{I}\|_{\max}$、$\Ijh=\hat{\mathbf{I}}_{\mathrm{opt}}(\varphi,\theta,\mathbf{p}_i)$：
\[
\mathbf{f}_{ij,\max}\!\left(\mathbf{p}_i,\varphi,\theta,I_{\max}\right)
=\frac{\|\mathbf{I}\|_{\max}^2}{\left\|\hat{\mathbf{I}}_{\mathrm{opt}}(\varphi,\theta,\mathbf{p}_i)\right\|^2}\,\rh
\]
$\mathbf{f}_{ij,\max}$ 為位置 $\mathbf{p}_i$、電流大小不超過 $\|\mathbf{I}\|_{\max}$ 時，沿方向 $\rh(\theta,\varphi)$ 所能產生的最大力量。

% ---------------------------------------------------------------------------------------
\section*{步驟 5}

定義
\[
\rho\!\left(\mathbf{p}_i,\rh\right)=\frac{\left\|\hat{\mathbf{f}}_{ij}\right\|}{\left\|\hat{\mathbf{I}}_{\mathrm{opt}}\right\|^2}
\qquad(\mathrm{pN/A^2})
\]

% ---------------------------------------------------------------------------------------
\section*{步驟 6}

\[
\mathrm{capacity}(\mathbf{p}_i)
=\left(\frac{1}{4\pi}\int_{-\pi/2}^{\pi/2}\int_{0}^{2\pi}\rho^3\!\left(\mathbf{p}_i,\rh\right)\cos\varphi\;d\theta\,d\varphi\right)^{1/3}
\qquad(\mathrm{pN/A^2})
\]
\[
\mathrm{isotropy}(\mathbf{p}_i)
=\frac{\displaystyle\min_{\rh}\ \rho\!\left(\mathbf{p}_i,\rh\right)}{\displaystyle\max_{\rh}\ \rho\!\left(\mathbf{p}_i,\rh\right)}
\]

\end{document}

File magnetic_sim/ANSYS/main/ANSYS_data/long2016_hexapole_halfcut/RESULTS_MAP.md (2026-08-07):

# RESULTS_MAP — long2016_hexapole_halfcut

**Single source of truth：這個 topic 底下每個 result dir 是什麼、能不能信、載入後該看到什麼指紋。**

讀任何結果前**先查這張表**（規則：`.claude/rules/result-read-safety.md`）。
本表凌駕 memory —— 若 memory 舊指標與本表衝突，以本表為準並更新 memory。
最後核對：2026-06-12（用 `wc -l` + `import_ansys_data` + bsum 欄掃描，read-only）。

> **⚠ 2026-07-14 資料夾結構已翻轉：`data/coil<N>/<variant>/` → `data/<variant>/coil<N>/`**（使用者拍板）。
> 即 dir 現為 `data/<variant>/coil<N>/`（例 `data/standard/coil2`、`data/gap_calibrate/coil1`、`data/no_gap/coil6`）。
> 下表各列的「dir」名（`coil1`、`coilN/gap_300um`、`coil2_gap_200um` …）為**舊順序寫法**，實際路徑請讀成 `<variant>/coil<N>`；
> **指紋（matched 節點 / |B| max）不受改名影響、仍有效**。
> 讀取碼一律 `import_ansys_data(fullfile(root,<variant>,'coil<N>'), <dataset>, 'coil<N>')`。
> **未動**（非 hexapole-coil 場資料）：`data/singlepole/`（頂層單極）、`data/coil1/singlepole/`（單極形狀樹）、`data/mesh/`。
> ⚠ baseline `standard` 只有 **coil2–6**（coil1 從未存 `standard` 子夾，屬既有缺口、非本次改名造成）。

---

## 怎麼用（層②核指紋）

`import_ansys_data(<dir>, <dataset>, <coilN>)` 讀
`<dir>/<coilN>_coord_<dataset>.dat` + `<coilN>_bfield_<dataset>.dat`，並印
`Matched %d nodes`。載入後**對照下表的「matched 節點」與「|B| max」**：

- 節點數可區分 **mesh 種類**（baseline vs graded）。
- 節點數**無法**區分 baseline vs `gap_200um`（同 mesh）→ **必須再看 |B| max**：
  gap 版整體低約 30%。

`dataset` 也是指紋的一部分：同一個 baseline 幾何有 `all`（全域）與 `wp`（WP 區域子集）兩種匯出，節點數不同，**回報時要連 dataset 一起講**。

---

## CANONICAL（可信，正式分析用）

| dir | coil/dataset | 物理意義 | matched 節點 (wp) | `_all` 行數 | WP 區 \|B\| max 指紋 |
|---|---|---|---|---|---|
| `coil1` | coil1, wp/all | **Long2016 verbatim baseline**（下極半切）P1 激發。**2026-08-06 重解補齊**（先前 `standard/` 缺此夾，整棵樹都沒有 baseline coil1） | 390579（air 341428） | 494873 | **1.1259 T** |
| `coil2` | coil2 | baseline，P3 激發 | 390579 | 494873 | **1.1366 T** |
| `coil3` | coil3 | baseline，P6 激發 | 390579 | 494873 | **1.1380 T** |
| `coil4` | coil4 | baseline，P5 激發 | 390579 | 494873 | **0.7489 T** |
| `coil5` | coil5 | baseline，P2 激發 | 390579 | 494873 | **0.7417 T** |
| `coil6` | coil6 | baseline，P4 激發 | 390579 | 494873 | **0.7410 T** |

> **⚠ 2026-08-06 更正兩筆錯誤指紋**（六顆全部重新實測 `import_ansys_data(...,'wp',...)` 的 `max(bsum)`）：
> `coil1` 原記 ~1.02 T → 實測 **1.1259**（1.02 應是誤抄本檔 gap sweep 列的 gap150 值 1.0102）；
> `coil5` 原記 ~0.45 T → 實測 **0.7417**。其餘四筆原記載正確。
> **佐證**：①`coil1` 的 1.1259 與本檔 `coil1/gap0um_mueq` 列的「gap0 **1.1259**（=baseline 驗證）」逐位相同；
> ②三顆下極（P1/P3/P6 = coil1/2/3）1.126/1.137/1.138 與三顆上極（P5/P2/P4 = coil4/5/6）0.749/0.742/0.741
> 各自成族，原記的 1.02 與 0.45 都是族外離群值。
> 舊的錯誤值會讓「層②核指紋」把**正確**的資料判成不符而擋下來 —— 這是本次重解 coil1 時抓到的。

> apdl coil 索引 ↔ 紙上極名：{1,2,3,4,5,6} = {P1,P3,P6,P5,P2,P4}（見 notation-glossary）。
> **2026-06-12 的泛化誤差分析、KI trend、B̄ matrix v4 baseline 用的就是這 6 個 dir 的 `wp` dataset。**

---

## VARIANT（可信，但**不是 baseline**，別跟上面混）

| dir | 物理意義 | matched 節點 | \|B\| max 指紋（判別關鍵） | 用途 |
|---|---|---|---|---|
| `coil2_gap_200um` … `coil6_gap_200um` | **舊 7mm 公式 μ_r 等效 200µm 氣隙**（protrusion 改 μ_r=31，單一材料）| 與 baseline **相同**（~390579/494873）| **比 baseline 低約 30%**（coil2 ~0.83 / coil5 ~0.25 T）| B̄ matrix v4 的 gap 對照（coil2–6 仍舊公式）|
| `coil1/gap{0,50,100,150,200}um_mueq` | **新 2 段式 μ_eff gap sweep（2026-06-26）**：coil1(P1, +1 raw) 激發，effective_permeability.pdf 兩段式公式，**上極/下極分開**施加在 6 protrusion 支撐座（upper3 μ_up / lower3 μ_lo；EMODIF 2882 lower + 3147 upper）。⚠ **覆寫了 coil1 的舊 gap100/gap200**（舊 7mm 公式作廢）| 與 baseline **相同**（494871/all，490579/wp）| \|B\|max 隨 gap **遞減**：gap0 **1.1259**（=baseline 驗證）/ 50 **1.0833** / 100 **1.0448** / 150 **1.0102** / 200 **0.9785** T。μ_eff: 50→137/165, 100→95/114, 150→73/88, 200→59/71（up/lo）。比舊公式溫和（舊 200µm ~0.71 vs 新 0.978）| gap 對 WP 場衰減研究 |
| `coilN/gap_300um` (N=1..6) | **300µm conformal REAL-slab base-gap**（2026-07-12）：6 極 base 各 **300µm 真實氣隙**（μ_r=1 實體 air slab，**非 μ_eff**；往 tip 移位、截面 conformal）。`graded_basegap` 網格（真 slab，有 sliver 但 magsolv 收斂）。6 極自激（no_gap 未做）| **`all`=1,213,785 / `wp`=357,704**（**unique**，≠ baseline 494873/390579、≠ `gap_200um`/mueq）→ 節點數即可辨識 | coil1 **0.9875** / coil6 **0.6442** T（WP 只比 baseline 低 ~3%：base gap 遠離 WP、影響溫和，**≠** μ_eff protrusion gap 的 ~30%）| 300µm 實體氣隙 gap vs baseline 比較。mesh `db/mesh_graded_basegap/mesh_graded.db`、deck `mesh/MT_Mesh_Graded_BaseGap.txt` + `sim/gap_200um/MT_Sim_P{1..6}_basegap.txt`（輸出 sed→`gap_300um`）|
| `P1_graded` | graded 密 mesh，**P1 only**，charge-fit 用 | 與 baseline **不同**（graded mesh）| ~1.20 T | KI 電荷擬合密網格 |
| `P2toP6_graded` | graded 密 mesh，P2–P6 | graded（不同）| ~1.21 T | KI 電荷擬合密網格 |
| `data/singlepole` | **單極模型**（下極填回完整圓錐+支撐座+鐵柱、無 yoke/上極；**均勻鐵件 0.3mm**）1A 自激 | `all`=704744 行（704747 節點−3 coil）/ `tip`=2741 | ~0.147 T（|B|max @ 極尖）| 單極場研究；**非 hexapole** |
| `coil1/lower_filled` | **下極填圓 hexapole**（完整 6 極 hexapole，但 3 下極填回完整圓錐、無 half-cut；coil1=−1 → P1 SOURCE）。**2026-06-26 改用 baseline smrt5 重 mesh + 重解**（取代舊 graded 1.39M）| `all`=845581（mesh 845599 節點）；節點數**與所有 halfcut 結果都不同**、易辨 | **0.8413 T**（與舊 graded 版一致 → mesh 無關、互validates）| 下極填圓場研究；y=0 場圖 `field_viz/figures/lowerfilled_P1_raw.png`。mesh `db/lower_filled/mesh_lowerfilled_smrt5.db`，deck `mesh/MT_Mesh_LowerFilled_smrt5.txt` + `sim/lower_filled/MT_Sim_LowerFilled_smrt5_coil1.txt` |
| `graded_rsp/coil1` | **公式化交叉測試（2026-08-04）**：與 `graded/coil1` **完全同一張網格、同一線圈、同一 BC**，只把 `magsolv` 由 **3(DSP)** 換成 **2(RSP)**（`MAGSOLV.MAC:47` 對應表）。P1 only | 與 `graded` **完全相同**（`all`=656235 / `wp`=371709 行，節點座標逐一相同）→ **節點數不可辨識，只能靠 dir 名** | `\|B\|max` **1.1414 T = 與 graded 逐位相同** | **結論：RSP ≡ DSP。** r≤150µm 平均場 DSP 8.821822 / RSP 8.821823 mT（差 **7.5e-6 %**）、逐點 \|ΔB\|max 1.07e-6 mT。→ 純量位家族自洽，**APDL-vs-Maxwell 的 14% 差距與公式化選擇無關**。deck 同 `sim/graded/MT_Sim_graded_all.txt`（`MAGOPT=2`）|

> ⚠ `data/singlepole` 命名異於 coilN：檔名 `singlepole_{coord,bfield}_{all,tip}.dat`（prefix=`singlepole`、dataset∈{all,tip}）。是**獨立單極幾何**（非 6 極 hexapole），節點數 704744 與所有 hexapole 結果都不同、易辨。mesh/solve 分離：`apdl/.../mesh/MT_Mesh_SinglePole.txt` + `sim/singlepole/MT_Sim_SinglePole.txt`，db `db/singlepole/{mesh,sim}_singlepole.db`。

⚠ **最易混點**：`coilN` vs `coilN_gap_200um` 節點數一模一樣，**只有 \|B\| 能分**。要 baseline 卻載到 gap 版 → \|B\| 會低 ~30%，層②必須在此攔下。

---

## NON-RESULT（**沒有 .dat，不是模擬結果資料**，不可當結果讀）

幾何 / mesh 匯出與 log，**不含 `*_bfield_*.dat`**：

- `geom_export_metre`, `geom_export_metre_HollowProt`, `geom_export_metre_gap200um`, `geom_export_metre_sph3`
- `geom_export_mm`, `geom_export_mm_HollowProt`, `geom_export_mm_HollowProt_Plain`, `geom_export_mm_gap200um`, `geom_export_mm_sph3`
- `geom_mm_hp_split`, `geom_mm_withcoil`
- `mesh_dense`, `mesh_graded`, `mesh_iges`
- `*.log`（batch / resume log）

被要求「讀結果」卻指向以上任一 → **判定非結果資料，停下來問使用者**。

---

## OBSOLETE / BROKEN（歷史，不可用於分析）

| 對象 | 狀態 | 證據 |
|---|---|---|
| `TwBError` | broken（0 個 .dat，名稱即 error run）| 目錄掃描無 .dat |
| `coil1_pre_fine_mesh`（**已不存在**）| 歷史：舊 B̄ v1/v2 曾以此為「正確 halfcut coil1」，現已移除 | memory `project_long_fei_B_bar`（過時指標）；現行正確 coil1 = 上方 CANONICAL `coil1`（494873）|
| B̄ matrix v1 / v2 / v3 | 被 v4 取代 | memory [[long-fei-b-bar-matrix-v4]]、[[halfcut-missing-vadd-bug]] |
| smrt4 全域跑 halfcut | 不可靠（MAPDL crash）| memory [[smrt4-unreliable-halfcut]]；標準是 smrt5 + 0.6A |

> 關於 `coil1_pre_fine_mesh`：這正是「讀錯結果」的典型成因 —— memory 指向一個**已換版/已刪除**的 dir。現在以**本表**為準：baseline 正確 coil1 就是 `coil1`（494873 節點）。

---

## 維護
- 新增 / 重跑 / 刪除 result dir 時**同步更新本表**。
- 新 topic（full / kuo_quadrupole / zhang…）要各自建 `RESULTS_MAP.md`（本次僅 halfcut）。

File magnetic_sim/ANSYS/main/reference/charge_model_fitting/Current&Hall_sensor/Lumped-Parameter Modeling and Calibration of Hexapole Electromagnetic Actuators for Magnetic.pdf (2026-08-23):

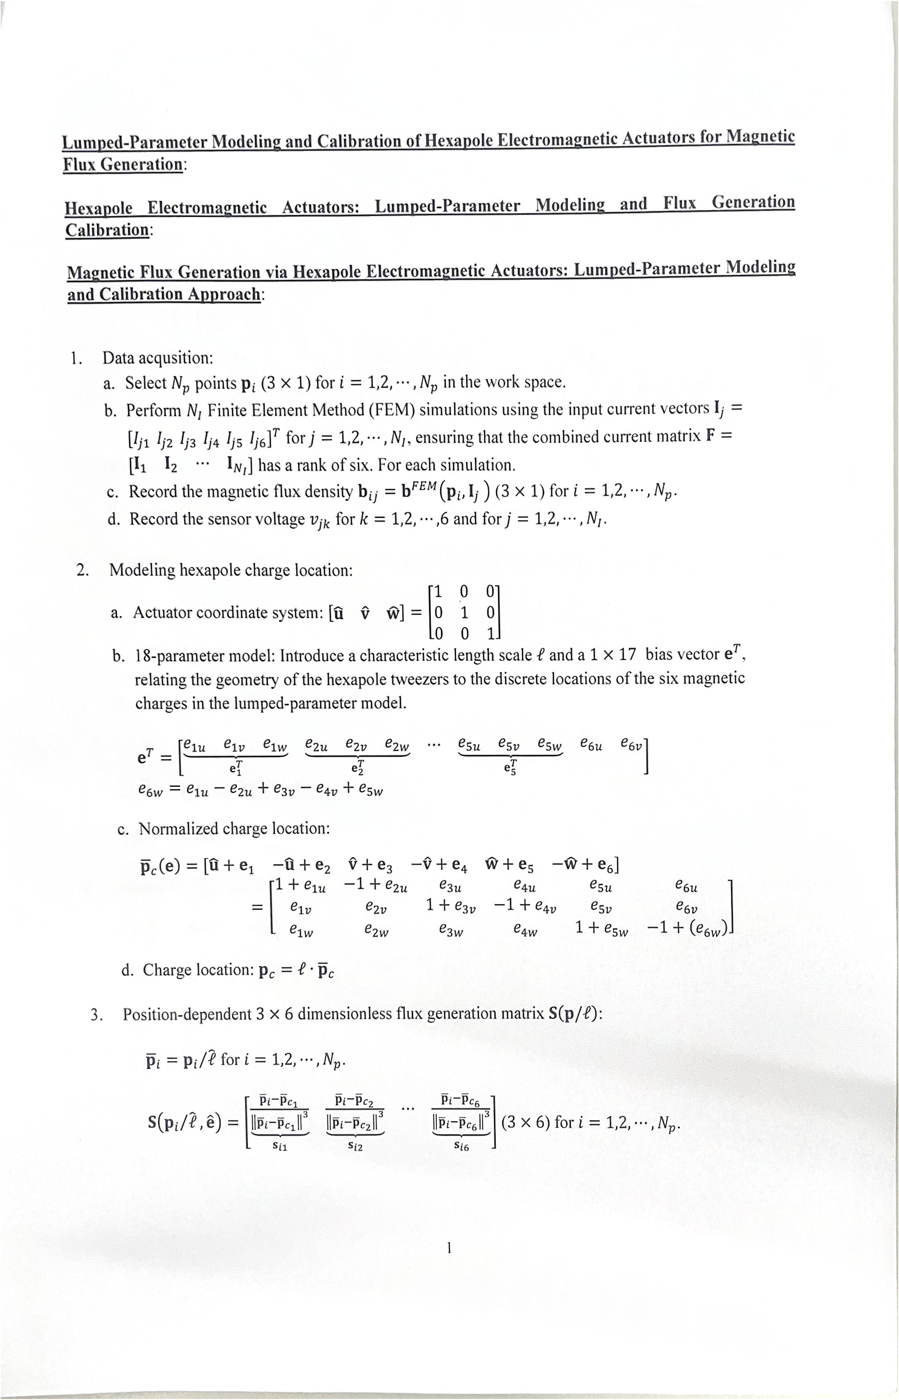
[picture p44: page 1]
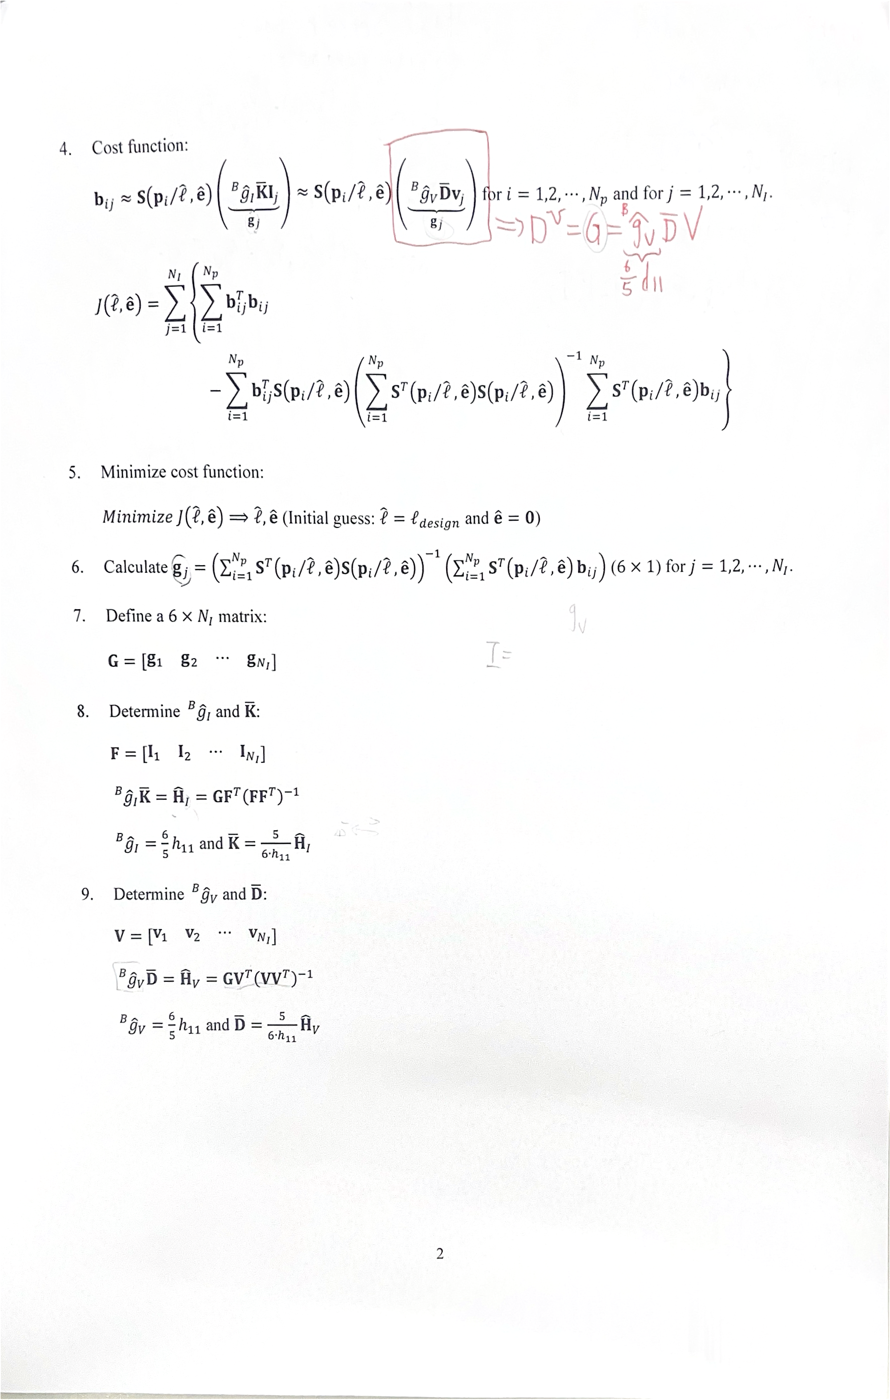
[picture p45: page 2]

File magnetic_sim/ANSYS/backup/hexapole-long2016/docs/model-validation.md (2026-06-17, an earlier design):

# Model Validation: APDL Simulation vs Long 2016 Dissertation

Date: 2026-03-07
Status: Pre-analysis validation complete. Ready to proceed with charge model fitting.

## 1. Origin of the Simulation Files

- APDL scripts received from Fei Long (original paths: `C:\Users\feilong\Desktop\Fei Long Ansys\Magnetic Tweezers LowPermeability`)
- We modified: working directory (line 3), boundary conditions (lines 497-518), POST1 data extraction (lines 531-565)
- All modifications marked with `[ADDED]` or `[MODIFIED]`
- Original code preserved with `!****` comment prefix

## 2. Parameter Comparison

### Confirmed Match

| Parameter | APDL Value | Dissertation (p.14) | Status |
|---|---|---|---|
| Pole material | 1018 steel | 1018 steel (0.18% C) | MATCH |
| Pole tip radius | 40 um (`POLE_TIP_R`) | 40 um | MATCH |
| Pole diameter | 6 mm (`POLE_R*2`) | ~6 mm | MATCH |
| Workspace radius | 500 um (`R_norm`) | 500 um (nominal) | MATCH |
| Coil turns | 70 (`TURNS`) | 70 | MATCH |
| Coil inner/outer radius | 5/8 mm | (not stated, but consistent) | MATCH |
| Unit excitation | 1 A per coil | 1 A (Fig.2.3) | MATCH |
| Element types | SOLID96 + SOURC36 | (not stated in dissertation) | N/A |
| Solver | magsolv,3 (DSP) | (not stated) | N/A |

### Issues Investigated

#### Issue 1: Material Model — murx = 280 (constant linear)

| Aspect | Finding |
|---|---|
| **Source of 280** | Iowa State 2006 paper: measured mu_r' = 280 for 1018 steel at low frequency (1-10 Hz) |
| **Directory name** | "LowPermeability" — intentional choice of low-field linear approximation |
| **Dissertation says** | Nothing. FEM material model not specified anywhere in 167 pages |
| **Real B-H curve** | mu_r varies: ~1250 at B=0.25T, ~1500 peak at B~1T, drops to ~100 at B=2T |
| **At our operating point** | Pole tips B~1T: real mu_r~1400 vs APDL 280 (5x underestimate) |
| **At WP center** | B~9mT: mu_r~280 (correct, low-field regime) |
| **System linearity** | Dissertation p.39: "flux density increased linearly with input current... up to 3A" |
| **Impact on WP field** | Small — air reluctance R_a >> steel reluctance R_steel |
| **Impact on tip |B|** | Moderate — peak values underestimated |
| **Impact on charge model fit** | R_a absorbs the difference; field SHAPE is geometry-dominated |
| **Conclusion** | Acceptable for current work. Non-linear B-H version can be done later for comparison |

#### Issue 2: Boundary Condition D,ALL,MAG,0

| Aspect | Finding |
|---|---|
| **Original script** | No boundary condition present |
| **We added** | Lines 497-518: MAG=0 on outer air cylinder surfaces (lateral + top/bottom caps) |
| **Why needed** | DSP solver (magsolv,3) requires explicit BC for unique solution |
| **Without it** | "Negative pivot at node 316044 MAG" warning |
| **Dissertation says** | Nothing about BCs |
| **Conclusion** | Physically correct. Required addition |

#### Issue 3: Lower Pole Geometry — Milled Flat

| Aspect | Finding |
|---|---|
| **APDL code** | Line 186-188: `VSBV` subtracts upper half of cone at z = -13 mm |
| **Effect** | Lower poles are HALF cones (flat on top, rounded below) |
| **Dissertation p.14** | "lower poles are 42mm long and are milled to form a flat platform to support the culture dish" |
| **ANSYS screenshot** | Confirmed: lower pole cross-section shows flat top surface |
| **Conclusion** | APDL model correctly includes the milling operation |

#### Issue 4: Upper/Lower Pole Asymmetry in max |B|

| Aspect | Finding |
|---|---|
| **Our result** | Lower poles (P1,P3,P6): max |B| ~1.13 T; Upper (P2,P4,P5): ~0.74 T |
| **Seems inverted?** | No — physically correct for the modeled geometry |
| **Explanation** | Lower pole = half cone → tip has half the cross-section area → B = Phi/A is higher |
| **Dissertation K_I** | Lower diagonal ~0.60 < Upper ~0.90 — measures WP flux FRACTION, not tip |B| |
| **Consistency** | Both observations are consistent: lower poles deliver less total flux (higher reluctance from milling) but concentrate it in a smaller tip area (higher peak |B|) |
| **WP center field** | All 6 coils produce ~8.7 mT (ratio 1.04) — consistent with R_a dominance |

## 3. Geometric Dimensions

### Lower Poles (P1, P3, P6)

- Orientation: **horizontal** (all key points at z = -13 mm)
- Tip position: r = 0.408 mm from z-axis, z = -13.0 mm
- Cone: 40 um tip radius → 3 mm base, length ~15 mm
- Shape: **half cone** (upper half removed by VSBV)
- Holder: 4 blocks, max cross-section ~160 mm^2
- Magnetic path (protrusion + cone): ~44 mm
- Dissertation: "lower poles ~42 mm" (p.14)

### Upper Poles (P2, P4, P5)

- Orientation: **inclined 36.6 deg** from horizontal
- Tip position: r = 0.408 mm, z = -12.4 mm
- Cone: 40 um tip radius → 3 mm base, length ~15 mm (same as lower)
- Shape: **full cone** (no cut)
- Holder: 3 blocks, max cross-section ~120 mm^2
- Pole axis length: ~44.3 mm; total magnetic path: ~51 mm
- Dissertation: "upper poles ~45 mm" (p.14)

### Workspace Center

- ANSYS coordinates: (0, 0, -12.711 mm)
- Defined by: `SPH_OFST = Z0_LOW - 6mm + R_norm_z`
- Symmetric between upper and lower tips (offset +-R_norm_z = +-0.289 mm)

## 4. Simulation Results Summary (6 Unit-Excitation Solves)

| Coil (APDL) | Paper Pole | Layer | Max |B| [T] | WP |B| [mT] | Nodes | Status |
|---|---|---|---|---|---|---|
| 1 | P1 | Lower | 1.12 | 8.64 | 494,871 | PASS |
| 2 | P3 | Lower | 1.14 | 8.74 | 494,871 | PASS |
| 3 | P6 | Lower | 1.14 | 8.63 | 494,871 | PASS |
| 4 | P5 | Upper | 0.75 | 8.87 | 494,871 | PASS |
| 5 | P2 | Upper | 0.74 | 8.93 | 494,871 | PASS |
| 6 | P4 | Upper | 0.74 | 8.96 | 494,871 | PASS |

- Max |B| ratio (lower/upper): 1.13/0.74 = 1.53
- WP field consistency ratio: 8.96/8.63 = 1.04
- All boundary fields < 1e-3 T (BC verified)
- No NaN or negative values

## 5. Figures Generated

| Figure | File | Description |
|---|---|---|
| 6-coil bar chart | `figures/verify_all_coils_comparison.png` | Max |B| and WP field per coil |
| Coil 1 vector plot (a) | `figures/verify_coil1_a.png` | Top view B-field distribution |
| Coil 1 WP vectors (b) | `figures/verify_coil1_b.png` | 3D vectors near WP center |
| Coil 1 tip vectors (c) | `figures/verify_coil1_c.png` | Field convergence at P1 tip |
| Coil 1 decay + axis (d) | `figures/verify_coil1_d.png` | Radial decay and x-axis profile |
| Coil 1 WP xy top view | `figures/verify_coil1_wp_xy.png` | WP region field vectors |
| Pole geometry | `figures/pole_geometry_comparison.png` | Upper vs lower pole schematic |
| Pole shape detail | `figures/pole_shape_detail.png` | Cone cross-section and tip zoom |
| murx analysis | `figures/murx_analysis.png` | mu_r(B) curve vs APDL constant 280 |

## 6. B Perpendicularity at P1 Cone Surface

**Script:** `analysis/verify_B_perpendicularity.m` (2026-03-21)

Verified that B on the air side of the P1 cone surface is approximately
perpendicular to the surface, as expected from the iron-air boundary
condition (murx=280, theoretical deviation = arctan(1/280) ≈ 0.2°).

### Method

- Load Coil1 full mesh (~494k nodes), select fine sphere (R < 7mm)
- For each axial bin (s = 1-6 mm from P1 tip, bin width 0.25 mm):
  - Select confirmed-air nodes: |B| < 50 mT, dr > 0 (outside cone)
  - Restrict to lower half (phi < -10°) to exclude VSBV flat-cut surface
  - Take closest 20% shell (adaptive, min 3 nodes)
  - Compute analytical cone normal and angle between B and normal

### Key definitions

- s: axial distance from P1 tip along cone axis (tip→base)
- dr: radial distance from analytical cone surface (positive = air side)
- phi: azimuth around cone axis (phi < 0 = lower half, intact cone)
- angle: deviation of B from surface normal (0° = perpendicular)

### Results

- **Angle: 7-11° across s = 1-6 mm**, mean 9.4°, std ~2-3° per bin
- **|B|: 28 mT (s=1mm) → 9 mT (s=6mm)**, smooth decay
- All nodes confirm B is directed **inward** (P1 = flux sink)
- No systematic s-dependence: angle stable across entire cone body

### Why not the theoretical 0.2°?

The ~9° deviation is NOT a model error. It comes from finite mesh resolution:
- Closest air nodes are 90-400 um from the true iron-air interface
- The 0.2° boundary condition holds only exactly AT the interface
- At 100+ um distance, the global field pattern adds tangential components
- Finer mesh (SmartSize < 5) would bring closest nodes nearer → smaller angle

### VSBV flat-cut effect

Lower poles have the upper half milled flat (VSBV at APDL line 186-188).
The flat cut is at z_wp = tip_z (vz = 0 in tip-centered coordinates).
- s < 3.5 mm: cone cross-section is nearly full circle → no effect
- s > 3.5 mm: upper half progressively removed → D-shaped cross-section
- Air nodes near the flat surface have FLAT normals, not CONE normals
- The script avoids this by selecting only phi < -10° (lower half)

## 7. Open Questions for Future Work

1. **Non-linear B-H version**: Run with `TB,BH` material data for 1018 steel, compare WP field and K_I fit
2. **K_I extraction**: Fit flux distribution matrix from 6-coil data, compare to dissertation Eq.2.8 and Eq.2.19
3. **Force model**: Compute g_I and force envelopes

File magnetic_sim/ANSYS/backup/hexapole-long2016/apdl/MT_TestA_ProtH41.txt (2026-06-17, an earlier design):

!****/CWD,'C:\Users\feilong\Desktop\Fei Long Ansys\Magnetic Tweezers LowPermeability'
!****/CWD,'D:\Fei Long ANSYS\Magnetic Tweezers LowPermeability'
/CWD,'C:\Users\pmero\Documents\Lab406\FEM_sim\magnetic_sim\hexapole-long2016\results\testA'   ! [MODIFIED] Test A: PROT_H=41mm

Finish
/cle

/CLEAR,NOSTART

/TITLE, 3D Magnetic tweezers magnetic field analysis
/FILNAME,3D MT magnetic field,1

/PREP7

! **** CHange BackGround color to white: ****
/RGB,INDEX,100,100,100, 0   
/RGB,INDEX, 80, 80, 80,13   
/RGB,INDEX, 60, 60, 60,14   
/RGB,INDEX, 0, 0, 0,15  
/REPLOT

! -------------------------------
! ******** MODELING: ************
! -------------------------------
MESH_SIZE = 5

POLE_NUM = 6
COUNTER  = 0

*dim, POLE_ARRAY,,  POLE_NUM
*dim, PROT_ARRAY,,  POLE_NUM

*afun, DEG   !----Using degree
BTOL, 1e-6   !----BoOL tolerence
/UNITS, MKS

R_norm    = 500e-6       !----working radius
R_norm_xy = R_norm*sqrt(2.0/3.0)
R_norm_z  = R_norm/sqrt(3.0)

YOKE_IN_R  = 84e-3/2.0    !----Inner radius of yoke
YOKE_OUT_R = 106e-3/2.0
YOKE_MID_R = (YOKE_IN_R + YOKE_OUT_R)/2.0
YOKE_H     = 2.0e-3
PROT_R     = 10.0e-3/2.0
PROT_H     = 41.0e-3    ! [MODIFIED] Test A: 7mm → 41mm (like Hung GP)

POLE_R        = 6.0e-3/2
POLE_TIP_R    = 40.0e-6    !----40um
POLE_CONE_LEN = 15e-3
POLE_CONE_HYP = sqrt(POLE_CONE_LEN**2 + POLE_R**2)
ANG1 = acos(POLE_R/POLE_CONE_HYP)
ANG2 = 90 - ANG1
L = POLE_CONE_LEN*POLE_TIP_R/POLE_R
POLE_TIP_CENTER = L/cos(ANG2)
POLE_CONE2_LEN  = L*cos(ANG2)
POLE_TIP_R2     = POLE_TIP_R*cos(ANG2)
POLE_TIP_FILLET_DROP = POLE_TIP_CENTER - POLE_TIP_R
POLE_TIP_FILLET_PROT = (POLE_CONE2_LEN - POLE_TIP_FILLET_DROP)

MT_CTR_ZOFST = -PROT_H - 6.0e-3 + R_norm_z

! -------------------------------
! ******* YOKE MODELING: ********
! -------------------------------
WPLANE, 1,0,0,0,,,,,,
WPcsys,-1,0

! **** 1 yoke: ****
CYL4,0,0,YOKE_IN_R,0,YOKE_OUT_R,360,YOKE_H

! **** 6 protrusion: ****
*do, prot_ind, 1, POLE_NUM,1
		
	WPLANE,1,0,0,0,,,,,,
	WPcsys,-1,0

        *if, prot_ind,LE,3, then
                temp_prot_h = -PROT_H
		temp_prot_ang = 120*(prot_ind - 1)
	*else
		WPOFFS,0,0,YOKE_H
		temp_prot_h = PROT_H
		temp_prot_ang = 120*(prot_ind - 4) + 60
	*endif

	CYL4,YOKE_MID_R*cos(temp_prot_ang),YOKE_MID_R*sin(temp_prot_ang),PROT_R, ,,,temp_prot_h
*enddo

! **** Unite the yoke and protrusion: ****
FLST,2, 1 + POLE_NUM, 6,ORDE, 2
FITEM,2, 1
FITEM,2,-(1+POLE_NUM)
VADD,P51X

*get, vol_yoke_ind, VOLU,,NUM, MAX

! ----------------------------
! **** 3 lower poles: ********
! ----------------------------
X0_LOW = YOKE_MID_R*cos(0)
Y0_LOW = YOKE_MID_R*sin(0)
Z0_LOW = -PROT_H

*do, pole_ind,1,3,1

	WPLANE, 1,0,0,0,,,,,,
	WPcsys,-1,0
        ROTA_ANG = 120*(pole_ind-1)
	WPROTA, ROTA_ANG,    !----Rotate about z axis

	*get, VL_NUM, VOLU, ,NUM, MAX
	VL_START = VL_NUM + 1
	numstr, VOLU, VL_START

	! **** Lower pole holer: ****
	BLOCK, X0_LOW - 5e-3,  X0_LOW + 11e-3, Y0_LOW - 5e-3,  Y0_LOW + 5e-3,  Z0_LOW - 10e-3, Z0_LOW          !----index: VL_START
	BLOCK, X0_LOW - 5e-3,  X0_LOW - 2e-3,  Y0_LOW - 10e-3, Y0_LOW + 10e-3, Z0_LOW - 10e-3, Z0_LOW - 5e-3
	BLOCK, X0_LOW - 10e-3, X0_LOW - 2e-3,  Y0_LOW - 5e-3,  Y0_LOW + 5e-3,  Z0_LOW - 10e-3, Z0_LOW - 2e-3
	BLOCK, X0_LOW - 10e-3, X0_LOW - 5e-3,  Y0_LOW - 10e-3, Y0_LOW + 10e-3, Z0_LOW - 10e-3, Z0_LOW - 5e-3

	! **** Key points & line: ****
	*get, KP_NUM, KP  , ,NUM, MAX
	*get, LI_NUM, LINE, ,NUM, MAX
	KP_START = KP_NUM + 1
	LI_START = LI_NUM + 1
	numstr, KP,   KP_START
	numstr, LINE, LI_START

	l1 = R_norm_xy
        l1_ang = atan2( 0 , R_norm_xy )

        l2 = sqrt( (R_norm_xy + POLE_TIP_FILLET_PROT)**2 + POLE_TIP_R2**2 )
	l2_ang = atan2( POLE_TIP_R2 , (R_norm_xy + POLE_TIP_FILLET_PROT) )

	POLE_CONE_LEN_SHIFT = POLE_CONE_LEN + (R_norm_xy - POLE_TIP_FILLET_DROP)
	l3 = sqrt( POLE_CONE_LEN_SHIFT**2 + POLE_R**2 )
	l3_ang = atan2( POLE_R , POLE_CONE_LEN )

	l4 = sqrt( (X0_LOW - 10e-3)**2 + POLE_R**2 )
	l4_ang = atan2( POLE_R , (X0_LOW - 10e-3) )

	l5 = abs( X0_LOW - 10e-3 )
	l5_ang = atan2( 0 , (X0_LOW - 10e-3) )

	l6 = abs( R_norm_xy + POLE_TIP_R )
	l6_ang = atan2( 0, R_norm_xy + POLE_TIP_R )

	K , , l1*cos(ROTA_ANG + l1_ang) , l1*sin(ROTA_ANG + l1_ang), Z0_LOW - 6e-3
	K , , l2*cos(ROTA_ANG + l2_ang) , l2*sin(ROTA_ANG + l2_ang), Z0_LOW - 6e-3
	K , , l3*cos(ROTA_ANG + l3_ang) , l3*sin(ROTA_ANG + l3_ang), Z0_LOW - 6e-3
	K , , l4*cos(ROTA_ANG + l4_ang) , l4*sin(ROTA_ANG + l4_ang), Z0_LOW - 6e-3
	K , , l5*cos(ROTA_ANG + l5_ang) , l5*sin(ROTA_ANG + l5_ang), Z0_LOW - 6e-3
	K , , l6*cos(ROTA_ANG + l6_ang) , l6*sin(ROTA_ANG + l6_ang), Z0_LOW - 6e-3  !---- for arc generation

	LARC , KP_START , KP_START + 1 , KP_START + 5 , POLE_TIP_R
	L , KP_START + 1 , KP_START + 2,,,,,,,,
	L , KP_START + 2 , KP_START + 3,,,,,,,,
	L , KP_START + 3 , KP_START + 4,,,,,,,,
	L , KP_START + 4 , KP_START,,,,,,,,

	! **** Create Area: ****
	*get, AR_NUM, AREA, ,NUM, MAX
	AR_START = AR_NUM + 1
	numstr, AREA, AR_START

	AL, LI_START, LI_START + 1, LI_START + 2, LI_START + 3, LI_START + 4

	! **** Rotate area to get volume: ****
	VROTAT, AR_START, ,,,,,KP_START,KP_START + 4,,4

	! **** Unite the volumn: ****
	*get, vl_ind_temp, VOLU,,NUM,MAX
	FLST,2,(vl_ind_temp - VL_START + 1),6,ORDE,2
	FITEM,2,VL_START
	FITEM,2,-vl_ind_temp
	VADD,P51X

	*get, vol_pole_ind, VOLU,,NUM,MAX
	VADD, VL_NUM, vol_pole_ind

	*get, vol_unite_ind, VOLU,,NUM,MAX

	BLOCK,0,X0_LOW - 10e-3,Y0_LOW - 10e-3,Y0_LOW + 10e-3,Z0_LOW - 6e-3, Z0_LOW

	VSBV, vol_unite_ind,vol_unite_ind + 1

	GPLOT

*enddo

! ---------------------------
! **** 3 upper pole: ********
! ---------------------------
	X0_HIGH = YOKE_MID_R*cos(0)
	Y0_HIGH = YOKE_MID_R*sin(0)
	Z0_HIGH = YOKE_H + PROT_H
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

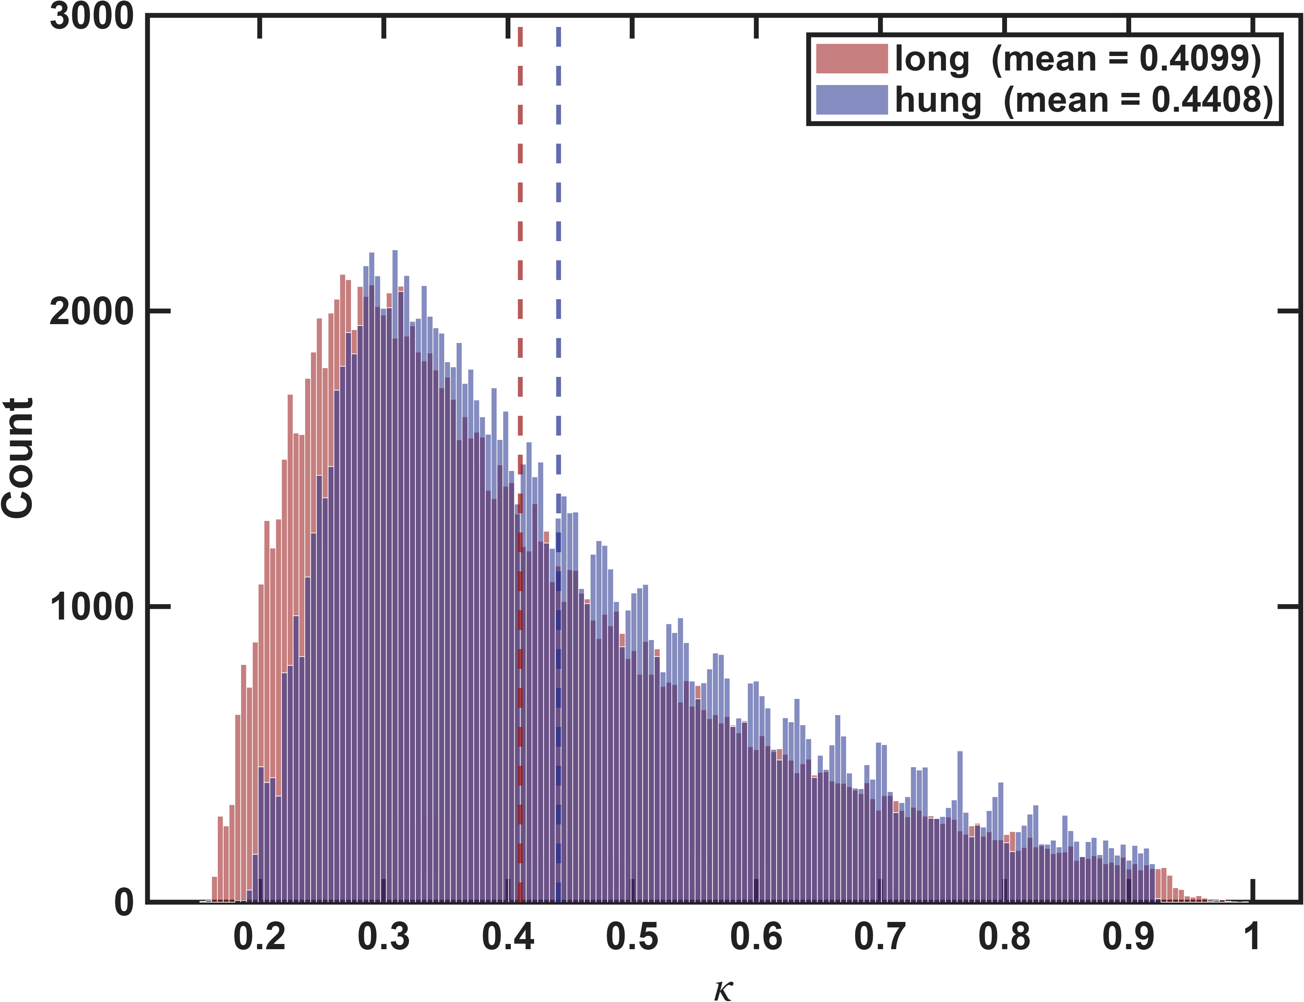
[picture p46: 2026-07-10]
magnetic_sim/ANSYS/main/matlab/Flux/APDL/Calibration_using_FEM_modeling/figures/long2016_hexapole_halfcut/current/common/iso_hung_vs_long_R500um.png

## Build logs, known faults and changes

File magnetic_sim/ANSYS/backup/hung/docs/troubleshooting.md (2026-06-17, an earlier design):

# Hung Hexapole — Troubleshooting Log

每次執行前必須閱讀此文件，避免重蹈覆轍。

---

## KMODIF 移動單一 tip KP → 表面扭曲

**問題：** 用 KMODIF 只移動 pole tip 的 KP，導致連接的 cone 表面變成 non-planar / twisted。

**原因：** tip KP 連接多條 line 和 area（cone surface、fillet arc 等）。只移動一個 KP 不會自動重建 surface of revolution。

**解法：** 不能只移動 tip KP。需要移動整根 pole 的所有 KP（整體平移），或重建 pole 幾何。

---

## VSBV 連續切削 → 第二刀退化

**問題：** 對同一 volume 做連續 VSBV，第二刀報 topological degeneracy。

**原因：** 第一刀產生的切割面和第二刀的 cutting block 邊界在 hex center 附近重疊。

**解法：** 用 NUMSTR 強制 cutting block 編號，每次 VSBV 前 ALLSEL 但只 VSEL 目標 pole volumes + cutting block。

---

## BTOL=1e-6 存在 db 中

**問題：** BTOL 設定會存在 db 裡，RESUME 後仍然生效。導致後續 VADD/VOVLAP 失敗。

**解法：** 做完需要 BTOL=1e-6 的操作後，立即 `BTOL, DEFA` 重設。

---

## *get NUM MAX 在 VSBV 後不可靠

**問題：** VSBV 刪除 volume 後留下空位，新建 volume 填入空位。`*get, VOLU, NUM, MAX` 回傳的不是新建的 volume。

**解法：** 用 `NUMSTR, VOLU, 500+i` 強制指定新 volume 編號。

---

## VOVLAP 37 volumes 極慢

**問題：** VOVLAP,ALL 對 35 steel + 2 air = 37 volumes 需要 >10 分鐘，可能不會完成。

**解法：** 先 VADD 所有 steel 成 1 volume，再 VOVLAP 少量 volumes（Long2016 方法）。

---

## Pole flat-cut Z=0 → topological degeneracy

**問題：** cutting block Z=0（切削面在 pole 軸線上）和 VROTAT quarter boundary 重合。

**解法：** Z 偏移 +0.2mm（5 根 pole）或 +0.5mm（GP6）。

---

## Pole flat-cut Z=-0.1mm → tip 被切鈍

**問題：** 負 Z 偏移在 tip 端（cone R < 0.1mm）會切掉整個截面。

**解法：** 只用正 Z 偏移。GP5 需 +0.1mm，GP6 需 +0.5mm。

---

## _RETURN 被 CSYS 覆蓋

**問題：** BLOCK 指令的 _RETURN 在下一個 CSYS 指令後被覆蓋為 0。

**解法：** 不依賴 _RETURN，用 NUMSTR 預設編號。

---

## KMODIF 整體平移 pole → 共享 KP 扭曲 block

**問題：** 即使移動整根 pole 的所有 KP（不只 tip），pole 和 block/yoke 的共享 KP 也會被移動，導致 block 表面扭曲。

**原因：** Pole 的 block-end KPs 和 T-block volume 共享。KMODIF 移動共享 KP 同時改變兩個 volume。

**解法：** 不能用 KMODIF。必須**刪除舊 pole volumes → 用調整後的參數重建**。

---

## Pole 重建時參數公式產生錯誤的 tip 位置

**問題：** 用 POLE_TILT + end_r + POLE_TOTAL_LEN 公式重建 pole 時，tip 位置在 z≈-27mm，但原始 db 的 tip 在 z≈-18mm，差 9mm。

**原因：** 原始 db 不是用 full15.out 的參數公式建的（或參數已改變）。公式和實際 db 幾何不匹配。

**解法：** 重建時直接指定 tip 座標（從最佳化結果），不要用參數公式計算。end 座標從原始 db 的 KP 讀取。

---

## 變數名衝突（TIP_Z 等）

**問題：** db 中已有 *DIM 定義的陣列（如 TIP_Z），用同名 scalar 會報 "needs subscripts"。

**解法：** 所有 flat-cut 變數加 `fc_` 前綴避免衝突。

---

## COIL_H vs COIL_DZ 混淆

**問題：** `COIL_H = 14mm` 是 block 頂到 yoke 底的間距（建模用），`COIL_DZ = 15mm` 是 SOURC36 coil 截面高度（Real constant RVAL2）。兩者名稱相似但意義完全不同。

**解法：** 程式碼中明確區分：
- `COIL_H` → 僅用於 yoke Z 位置計算（`fc_yoke_zbot = fc_up_blk_top + COIL_H`）
- `COIL_DZ` → 用於 Real constants 和 coil Z 位置（`block_top + COIL_DZ/2`）

---

## Upper block BLK_T/sin(TILT_UP) 對淺角度失效

**問題：** 原始 upper block 定位用 `fc_dt = BLK_T/sin(TILT_UP)` 計算 block 中心 XY。當 TILT_UP < 28° 時，fc_dt 過大，block 中心超出 yoke 外徑（62.5mm），pole 無法接上 block。

**原因：** 淺角度時 pole 幾乎水平穿過 block，需要很長的水平距離才能上升 BLK_T 的高度。

**解法：** 改用 pole end 居中定位（跟 lower block 一樣）：
```apdl
fc_zbot = fc_endz - BLK_T/2
fc_ztop = fc_endz + BLK_T/2
fc_cx = fc_endx
fc_cy = fc_endy
```
此方法不依賴 sin(TILT_UP)，任何角度都能正確定位。

---

## IGES unit flag 與 SolidWorks STEP 轉換

**問題：** ANSYS 匯出 IGES 時 unit flag = 6（mm），但實際數值為英寸（MM=1/25.4）。SolidWorks 開啟時忽略 flag 直接讀取為英寸 ×25.4 = 正確 mm。但另存為 STEP 時可能因 flag 不一致導致尺寸錯誤。

**解法：** 匯出後修正 unit flag 為 1（inches）：
```bash
sed -i "s/,1.0,6,,/,1.0,1,,/" file.iges
```

---

## Pole tip fillet：方案 A vs 方案 B

**問題：** 為 pole tip 加 40 µm 直徑 fillet 時，幾何上不可能同時滿足三個條件：
1. Fillet 在原 tip 位置
2. Cone 半角維持 11.31°（原始 STEP 量值）
3. Cone-cyl 接點維持在 X=15.875 mm

必須有一個讓步。

**方案 A（已採用）：smooth tangent fillet**
- Cone 半角不變（11.31°）
- Junction X 從 15.875 → 15.793 mm（內縮 0.082 mm）
- Fillet 與 cone 平滑相切（無銳角）
- Cylinder 段補回 0.082 mm，總長 43 mm 不變
- **這是 Long2016 的做法，幾何上正確**

**方案 B（不採用）：sharp corner**
- Cone 半角變成 12.96°（變陡）
- Junction X = 13.74 mm
- Cone 從 fillet foremost (0,0) 直接出發，與 fillet 形成銳角
- 改變了 pole 的物理形狀

**Long2016 公式（複用）：**
```
POLE_TIP_R = 20e-6                     ! 半徑（40 µm 直徑）
ANG2 = atan(POLE_R/POLE_CONE_LEN)      ! 11.31°
L_FILLET = POLE_CONE_LEN*POLE_TIP_R/POLE_R
POLE_TIP_CENTER = L_FILLET/cos(ANG2)
FILLET_DROP = POLE_TIP_CENTER - POLE_TIP_R = 0.082 mm
JUNC_X = POLE_CONE_LEN - FILLET_DROP = 15.793 mm
```

**實作：** `apdl/geom/MT_Hung_Assembly_Dfillet.txt`、`apdl/geom/export_pole_filleted.txt`

---

## Post-processing 從獨立 session 執行時找不到結果檔

**問題：** 用獨立 ANSYS session 跑 post_extract_wp.txt 時報 "No results file"。

**原因：** 預設 jobname 為 `post1`，但結果檔是 `coil1.rmg`。RESUME 找的是 `post1.db` 而非 `sim1.db`。

**解法：** 在 post script 開頭加 `/FILNAME, coil1`，確保 jobname 與結果檔一致。
```apdl
/FILNAME, coil1
RESUME, 'sim1', 'db'
/POST1
SET, LAST
```

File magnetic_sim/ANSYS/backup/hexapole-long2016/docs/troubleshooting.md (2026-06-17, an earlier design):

# Troubleshooting

## Negative Pivot at Node 316044
- **Symptom:** `*** WARNING: Negative pivot at node 316044 MAG`
- **Cause:** Missing or insufficient boundary conditions for DSP method
- **Fix:** Apply `D,ALL,MAG,0` on all outer air cylinder boundary surfaces (lateral + top/bottom caps)
- **Notes:** The DSP method (magsolv,3) requires explicit boundary conditions to obtain a unique solution

## Coefficient Ratio > 1e8
- **Symptom:** `Coefficient ratio exceeds 1.0e8`
- **Cause:** Extreme element size ratio: pole tip (40 um) vs outer air (80 mm) = 2000:1
- **Fix:** This is expected for this geometry. The SmartSize algorithm handles the transition. Monitor solution convergence but no action needed.

## SmartSizing Small Angle Warning
- **Symptom:** `Small angle detected in area near pole tip, mesh coarsened`
- **Cause:** Sharp cone geometry at pole tips (40 um radius fillet on 3 mm base cone)
- **Fix:** Expected behavior. ANSYS auto-coarsens to avoid degenerate elements. Does not affect solution accuracy significantly.

## "No Constraints" Warning
- **Symptom:** `No constraints have been defined` during /SOLU
- **Cause:** Forgot to apply MAG=0 boundary condition before entering /SOLU
- **Fix:** Exit /SOLU, apply boundary conditions in /PREP7, then re-enter /SOLU
- **Prevention:** Always verify the `[ADDED] Apply far-field boundary condition` block exists before magsolv

## Memory Exceeded
- **Symptom:** `Insufficient memory` or ANSYS crashes
- **Cause:** Large mesh in outer air sphere (~2.4M elements at SMRT=5)
- **Fix:** Use `-m 24000` flag (24 GB) when launching batch mode. If still failing, increase SMRT level (coarser mesh) or reduce AIR_CYL dimensions.

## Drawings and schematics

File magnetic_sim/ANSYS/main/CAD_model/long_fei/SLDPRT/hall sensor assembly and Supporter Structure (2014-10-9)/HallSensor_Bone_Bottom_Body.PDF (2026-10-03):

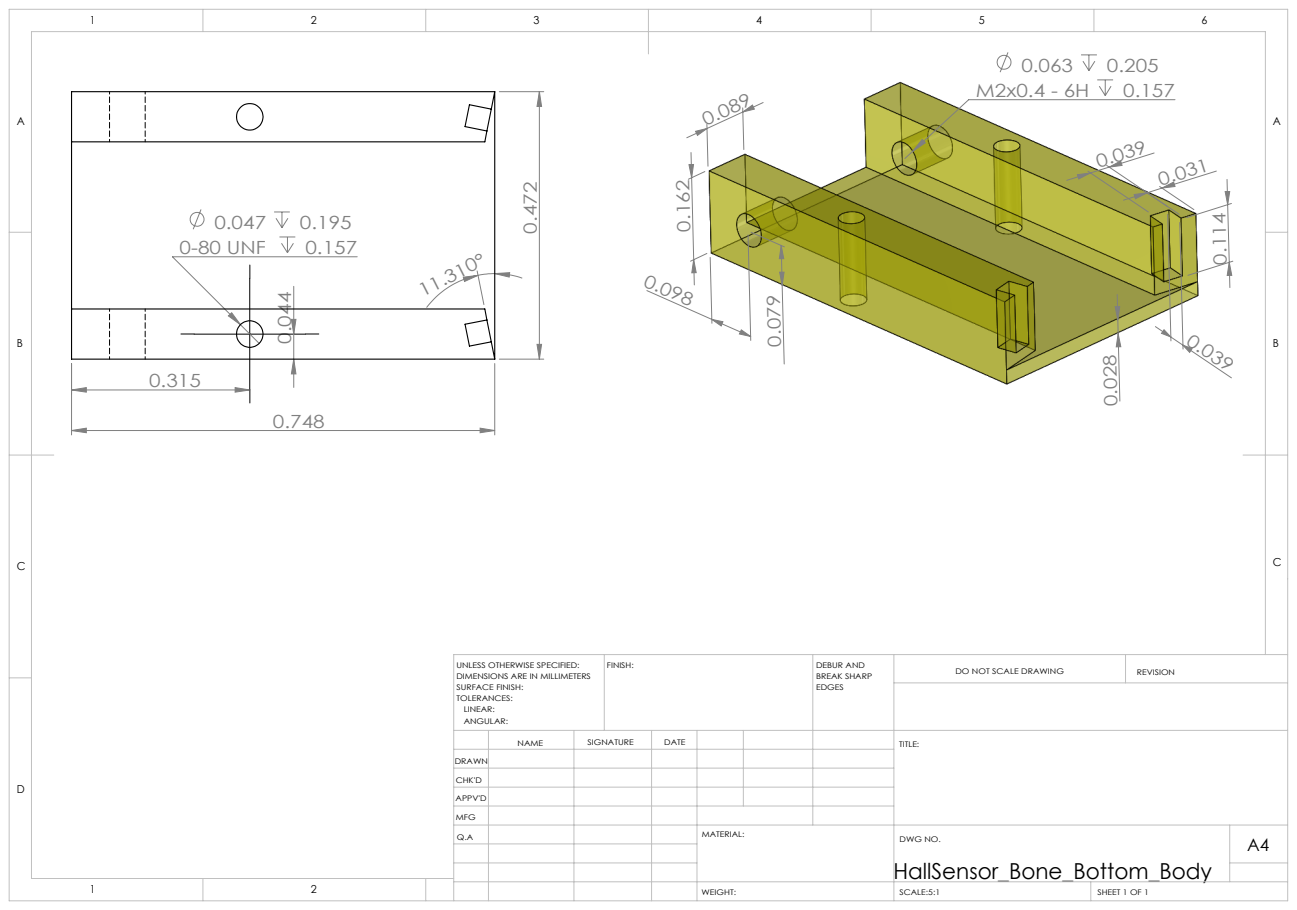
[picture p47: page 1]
0-80 UNF; FINISH:; DEBUR AND; BREAK SHARP; DO NOT SCALE DRAWING; REVISION; SCALE:5:1; SHEET 1 OF 1

UNLESS OTHERWISE SPECIFIED:
DIMENSIONS ARE IN MILLIMETERS
SURFACE FINISH:
TOLERANCES:
LINEAR:
ANGULAR:

NAME | SIGNATURE | DATE | | | | TITLE:

DRAWN
CHK'D
APPV'D
MFG
Q.A | | | | MATERIAL: | DWG NO. HallSensor_Bone_Bottom_Body | A4

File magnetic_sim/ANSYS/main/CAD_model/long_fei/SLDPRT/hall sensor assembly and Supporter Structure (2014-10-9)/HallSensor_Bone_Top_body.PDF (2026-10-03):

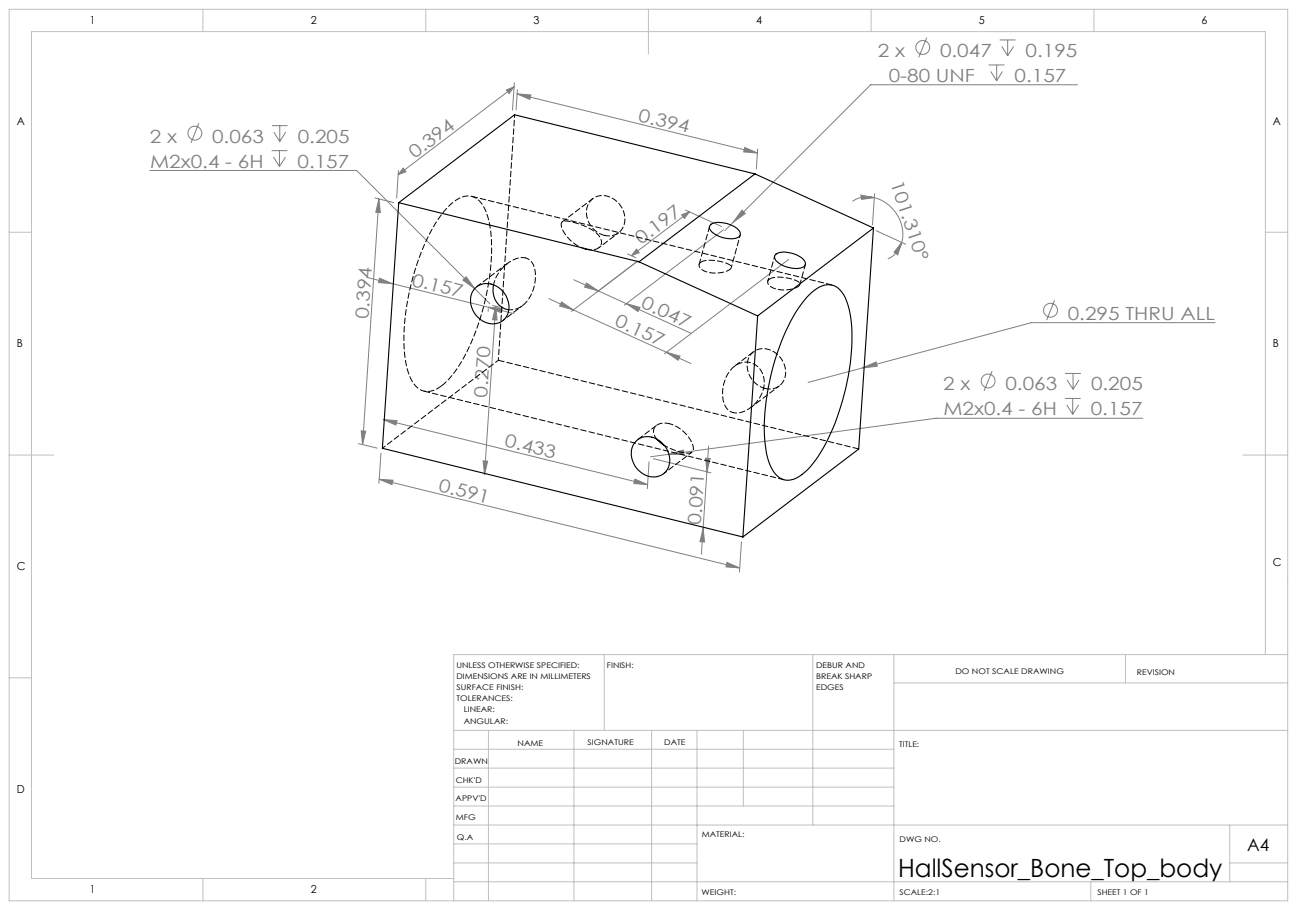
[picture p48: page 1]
0.295 THRU ALL; 0-80 UNF; FINISH:; DEBUR AND; BREAK SHARP; DO NOT SCALE DRAWING; REVISION; SCALE:2:1; SHEET 1 OF 1

UNLESS OTHERWISE SPECIFIED:
DIMENSIONS ARE IN MILLIMETERS
SURFACE FINISH:
TOLERANCES:
LINEAR:
ANGULAR:

NAME | SIGNATURE | DATE | | | | TITLE:

DRAWN
CHK'D
APPV'D
MFG
Q.A | | | | MATERIAL: | DWG NO. HallSensor_Bone_Top_body | A4

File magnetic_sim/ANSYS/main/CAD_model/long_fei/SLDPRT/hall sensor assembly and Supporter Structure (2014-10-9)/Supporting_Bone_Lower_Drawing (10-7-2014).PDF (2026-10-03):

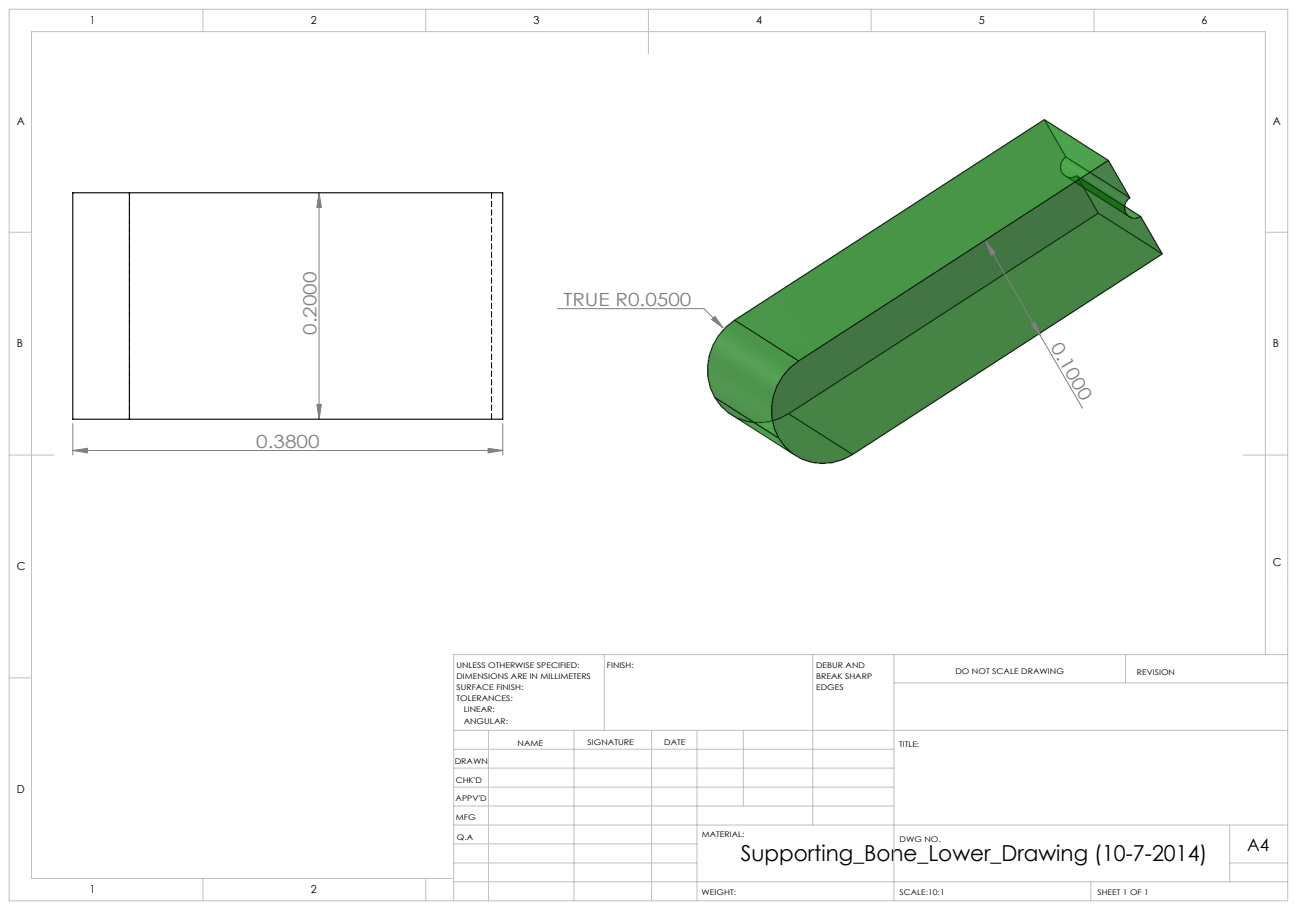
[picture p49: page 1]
TRUE R0.0500; FINISH:; DEBUR AND; BREAK SHARP; DO NOT SCALE DRAWING; REVISION; SCALE:10:1; SHEET 1 OF 1

UNLESS OTHERWISE SPECIFIED:
DIMENSIONS ARE IN MILLIMETERS
SURFACE FINISH:
TOLERANCES:
LINEAR:
ANGULAR:

NAME | SIGNATURE | DATE | | | | TITLE:

DRAWN
CHK'D
APPV'D
MFG
Q.A | | | | MATERIAL: Supporting_Bone_Lower_Drawing (10-7-2014) | DWG NO. | A4

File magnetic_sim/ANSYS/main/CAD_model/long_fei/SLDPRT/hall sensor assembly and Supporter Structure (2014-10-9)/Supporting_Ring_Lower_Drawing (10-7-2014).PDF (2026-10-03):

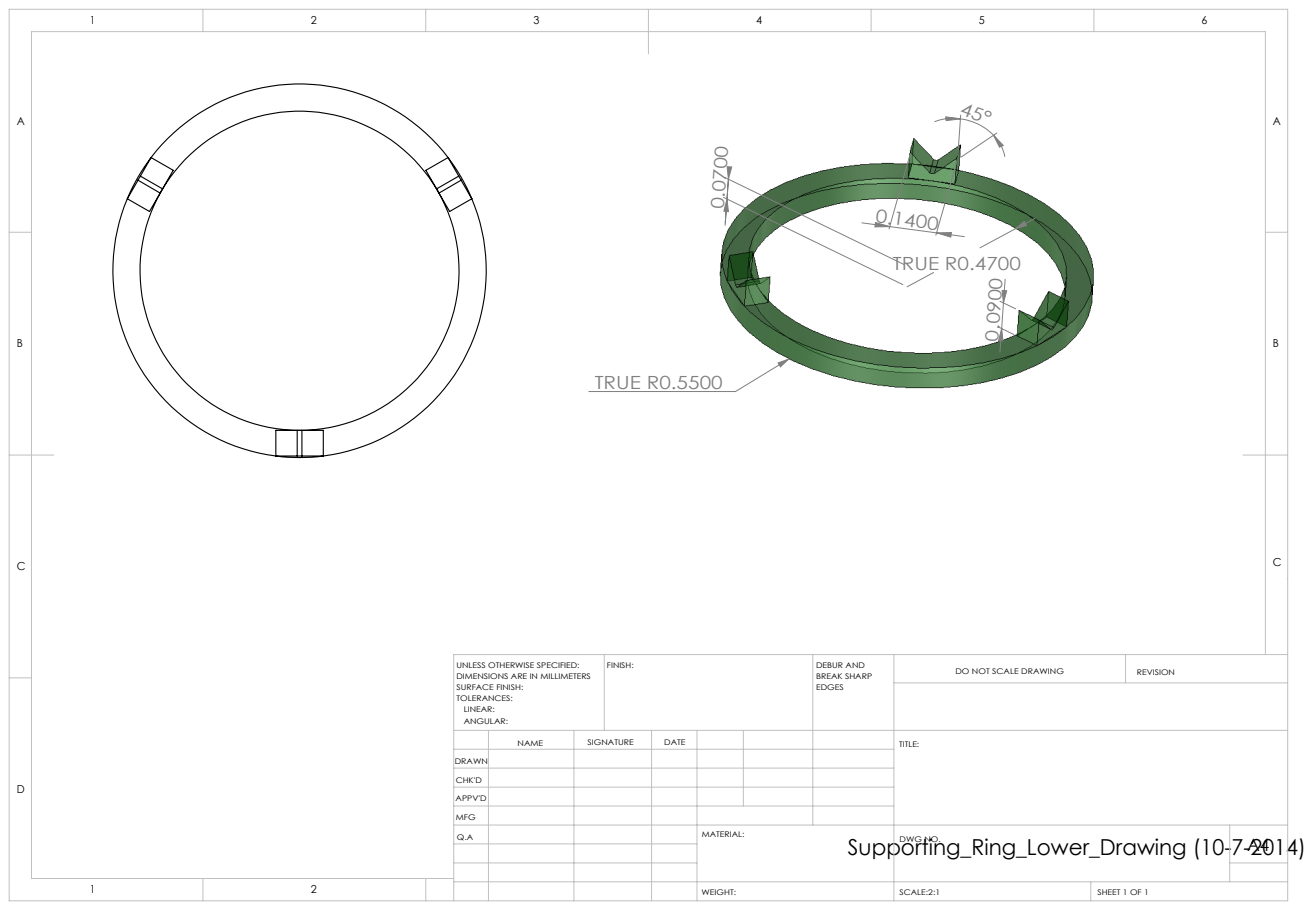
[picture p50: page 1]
TRUE R0.5500; TRUE R0.4700; FINISH:; DEBUR AND; BREAK SHARP; DO NOT SCALE DRAWING; REVISION; SCALE:2:1; SHEET 1 OF 1; Supporting_Ring_Lower_Drawing (10-7-2014)

UNLESS OTHERWISE SPECIFIED:
DIMENSIONS ARE IN MILLIMETERS
SURFACE FINISH:
TOLERANCES:
LINEAR:
ANGULAR:

NAME | SIGNATURE | DATE | | | | TITLE:

DRAWN
CHK'D
APPV'D
MFG
Q.A | | | | MATERIAL: | DWG NO. | A4

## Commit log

2026-06-17 Initial commit: FEM_sim — electromagnetic microprobe FEM simulation framework
    General-purpose FEM simulation container for hexapole/quadrupole
    electromagnetic microprobe control systems (ANSYS MAPDL + COMSOL).
    See PROJECT_STATUS.md for current structure and status.
    [0.46mm_20um.SLDPRT, 0.46mm_20um.STEP, 0.46mm_baseline.SLDPRT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]
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2026-06-18 Fix ansys_path consumers for ANSYS_data data/ reorg (coilN -> data/coilN)
    Insert 'data' segment in the 14 ansys_path(model,'coilN','standard') field-data reads across bias_fit, fixl_fit, and Calibration_using_FEM_modeling fix_dir/no_fix_dir (plots + calib + load_coils_actuator). Resolver (common/ansys_path.m) left generic.
2026-06-18 Migrate hardcoded ANSYS_data paths for data/ reorg (57 .m files)
    User reorganised ANSYS_data/long2016_hexapole_halfcut into data/(coilN,mesh)+db/(.db). Literal-insert 'data' into hardcoded results_root/res_base/rr roots (+\data) and direct \coilN paths (\data\coilN) across field_viz, validation, bs_matrix, fixl_fit, sensor_placement, Calibration (Hall_sensor_base, fix_dir, no_fix_dir). Verified 0 stale paths; 57 files now point to ...halfcut\data\. ANSYS_data is read-only for MATLAB so roots safe; gap200um_mueq/*_graded data no longer present (broken at data level, out of scope).
2026-06-19 Refactor Hall_sensor_base_fix_dir + reorganize charge_fit/ into subfolders
    Hall_sensor_base_fix_dir (收斂成單一指定流程):
    - main.m 改載入 fix_dir 的 ell_hat (fit_KI_R150.mat),不再自己 fminbnd
    - extract_Vmat 改用真實 FEM 節點 (沿法線 n 圓柱選點),移除 scatteredInterpolant 內插
    - build_sensor_geometry 精簡為只回 sensor_pos/sensor_n
    - sensor_residual 只回 cost J = sum||eps||^2 (移除相對 RMSE)
    - 刪除 cost_J/compute_KH/write_d_tex/write_KH_tex + 2 verify + plot/results/figures
    - 全檔加中文詳細註解
    charge_fit/ 整理 (頂層不再混 散檔+子夾,全部歸子夾):
    - 刪 validate_combos.mat (舊版,被 _R150 取代)
    - 新增 calibration/ (cal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
2026-06-22 sensor_spheres mesh refinement + self-fit l_hat for Hall-sensor calibration
    - Sensor mesh refinement: 6 local R=0.16mm air spheres @ ESIZE 0.04mm at the Hall-
    sensor positions -> ~175 real nodes/sensor in the sampling cylinder (baseline had 1),
    fixing the d / D_H 1-node sign artifact. Field matches baseline to 0.16%.
    New decks: geom/mesh/MT_Mesh_SensorSpheres, sim/sensor_spheres/{MT_Sim_P1, MT_Resolve_P2toP6},
    gui/MT_View_SensorSpheres. VGLUE replaced by mesh+NUMMRG (VGLUE hangs on half-cut iron).
    - extract_Vmat sampling = cylinder D0.3mm x 0.1mm from the sensor face toward n+
    (>=0.41mm from iron); real-node, one-sided.
    - fix_dir/main.m: fit l_hat via fminbnd on profiled cost (sens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
    [Long2016_HexapoleHalfcut_Geom_WPsphere.iges]
2026-06-30 Hall-sensor calibration: D-matrix, flip-sink, g_V, current=voltage check
    - All projects use flip-sink sign convention (fix_dir converted)
    - Hall D-matrix finalized: 10k-point interp, g_V gauge gain, V normalized to %
    - Verified charge model = sensor(voltage) model: same field error
    - 3D magnetic-circuit plots (per-pole structure, 2 views)
    - Plus pending MATLAB_data -> matlab/.../data reorg + sensor mesh + gap200 decks
    [HexapoleLowerFilled.iges, SinglePoleFilled.iges, sensor_local_elems.csv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]
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2026-07-01 Calibration: separate result-PDF output into emit_model_results; 3D charge figures; figure/number rules
    - 3D magnetic-charge position figures (fix/no_fix plot_charge_positions_3d.m):
    P1/P2 pole cones + pink charge dots + l_hat dashed lines to WP; no_fix marks
    total offset Delta vs fix. Frame = manual draw_box_edges (omit farthest corner)
    + box off + daspect (not axis equal).
    - rules/figure-style.md: 3D box recipe + number-labeling conventions (no 10^0 factor,
    no unit label when dimensionless); README + read-rules-first synced.
    - Output separation: each calibration main now only computes + saves .mat + console;
    result PDF moved to standalone code/function/emit_model_results.m per pa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
2026-07-02 fix_dir: SVD actuation-transfer analysis + control-range σ_tot/iso_tot + geometry figures
    Actuation transfer T_i(p)=S_i(p)·Ĥ_I (current→WP field, Ĥ_I=gB·Khat); SVD → gain=‖T‖_F,
    iso=σ_max/σ_min, U=field principal axes. σ/W frame-invariant, U carries R_act.
    - calc_range_metrics.m + main.m + emit_model_results.m: control-range representative
    values over R≤150µm ball (8774 real nodes, arithmetic mean, not sum): σ_tot=18.61 mT/A
    (σ_min=18.23), iso_tot=1.14 (iso_worst=1.28). PDF gains σ_tot/iso_tot lines.
    - svd_SiHI_WP.m: WP-center T SVD → U/Σ/Wᵀ (actuator frame; S_i=−Pc_base, ℓ̂-independent).
    - plot_svd_gain_iso_3d.m: gain/iso single-hill surfs on z=0 plane (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
2026-07-02 no_fix_dir bias: SVD hills + frames-lattice + σ_tot/iso_tot + all-source K̄/G fix
    18-param bias (no_fix) counterparts of the fix_dir actuation analysis, on the same
    T=S_i·Ĥ_I current→field transfer (bias charges Pc=Pc_base+E(ê), actuator frame).
    - plot_svd_gain_iso_3d.m: bias gain/iso hills over z=0 plane (dhat→dhat_bias=R_act'·make_Pc(ê));
    mirrors fix_dir style (iso flipped colormap, Gain label, z-ticks + min/max).
    - plot_frames_lattice_bias_3d.m: two-frame geometry with fixed ℓ̂ shell + 6 bias charges
    displaced off-shell (lower P1/P3/P6 ~140µm≈9°, upper P2/P4/P5 ~19µm); ±R150 ball variant.
    - calc_range_metrics.m (copied, frame-agnostic) + main.m: control-range σ_t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
2026-07-02 fix-vs-bias gain/iso: per-node index plots + RMS/RMSE deviation
    Quantify how close the fix-ℓ and 18-param bias models are over the R≤150µm control
    range (8774 real ball nodes), evaluated in the actuator frame (R_act·dhat = Pc_base
    so fix uses charges Pc_base, bias uses make_Pc(ê); gain/iso are frame-invariant).
    - plot_gain_iso_index.m: per-node gain/iso vs node index, 4 figures (fix & bias ×
    gain & iso), each annotating the variance (+ mean line). Notable: bias gain
    variance 0.114 vs fix 0.031 (mT/A)² — bias's per-node gain spreads ~3.7× wider
    (off-axis charges), while the means match (18.61 both).
    - compare_gain_iso_fix_vs_bias.m: prints RMSE (gain 0.293 mT/A, iso 0.0153)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
2026-07-03 fix_dir: do the B_model−B_FEM subtraction in the actuator frame
    Now all 4 calibration packages form the fit residual in the actuator frame
    (the other 3 already did). load_coils rotates P/B to actuator; main + err-hist
    pass Pc_base as the charge lattice. Frame rotation preserves norms, so the fit
    results are unchanged — verified: Δell=5e-7µm, ΔgB=4e-8, Δerr=0, ΔKhat=9e-9.
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2026-07-03 Remove dead PDF-output code from the 4 calibration main.m
    Each main.m had a leftover PDF/LaTeX local function (compile_tex_pdf in
    fix/no_fix, emit_labeled_matrix in the two Hall mains) that was never called —
    the actual PDF generation already lives, self-contained, in
    code/function/emit_model_results.m. Deleted the dead functions plus the now-unused
    PDF leftovers (tex_dir/out_dir + mkdir, the misleading "result PDF(s)" fprintf),
    and fixed the pipeline-header/README lines (main now saves .mat + console; PDF via
    emit_model_results.m). Kept onaxis_cost in Hall_fix (it's the fit cost, not PDF).
    Verified: all 4 main.m run clean, fix/no_fix results identical (ell/gB/err/sigma_tot),
    and all 4 em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
2026-07-03 Move emit_model_results (PDF output stage) into main_function/
    emit_model_results is the PDF-output stage of the main calibration workflow, so
    it belongs with main_function/ rather than function/. Moved it in all 4 packages
    (fix_dir, no_fix_dir, Hall_sensor_base_fix/no_fix_dir) and updated the location
    pointers in the mains + READMEs. It's never called by code (run standalone), and
    main_function/ is already on-path everywhere function/ is, so the move is purely
    organizational with no addpath/functional change.
    function/ now holds only the non-workflow helpers (svd_SiHI_WP, write_KI_tex,
    write_KbarI_tex, sensor Vmat/solve helpers).
    Verified: all 4 emit_model_results regenerate their PDFs fr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
2026-07-03 gain_index: share one y-axis across fix & bias plots
    The two gain-vs-index plots auto-scaled to different y-ranges, hiding that the
    bias model's gain spread is ~2x the fix model's. Lock both gain plots to a common
    y-axis (covering both datasets + small margin) so their scatter is directly
    comparable — matching how the two iso plots already sit on a common scale. iso
    plots unchanged.
2026-07-03 index plots: 6 y-tick intervals (match iso); SVD hills: x_m/y_m axis labels
    index (gain/iso vs node): revert the shared gain y-axis; each plot keeps its own
    data range but the y-axis is forced to 6 equal intervals (7 ticks), so gain and
    iso have the same number of tick intervals.
    SVD hill surfs (fix+bias, gain+iso): relabel the two horizontal axes x_m / y_m
    (measure frame, consistent with frames_lattice); vertical axis stays Gain (mT/A) / iso.
2026-07-03 Delete sensor_placement plotting group + clean up references
    sensor_placement/ (Hall-sensor placement/geometry/sensitivity pure-plotting group)
    is no longer needed. Removed the whole folder (~13 scripts + figures + READMEs); it
    had zero code coupling (nothing imported or called it). Updated the references that
    pointed at it: the two structure READMEs (matlab/ + long2016_hexapole_halfcut/),
    a comment in bias_fit/anim_charge_side.m, the field-plot workflow template row, and
    the generic pure-plotting examples in main/CLAUDE.md + rules/matlab-output-layout.md.
2026-07-03 index histograms: move stat box off the bars, add marker lines, finer bins
    - stat box -> top-left so it no longer overlaps the tall right-side C bars
    - C plot: dashed vertical line at the mean; kappa plot: dashed line at kappa=1
    (isotropy ideal), with the x-limit nudged so that line sits inside the frame
    - bins 120 -> 160 (finer, ~matching the field-error histogram)
2026-07-03 Cleanup: finalize removed files + gitignore ANSYS Maxwell exercise
    Commit the working-tree deletions (doc/sensor_location, Hall_sensor_base decouple
    scripts, fix_dir plot helpers make_R040_charge_figs/verify_G_vs_Dv, ellipsoids
    figure) and add magnetic_sim/ANSYS/Maxwell/ (+ *.aedtresults/) to .gitignore.
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2026-07-10 hung 反增益修復 + gap/nogap 命名統一
    - hung 下極：縮鐵棒(43→38) + 氣隙移 radial40 + 挖 100mm² → 加氣隙 tip 場 −1.5%(反增益翻負，P1/P3/P6 一致)
    - gain/iso 疊圖用新 gap 重出；修正 gap-vs-nogap 對照(同網格 lowfwd)：hung 2557<2617、long 2272<2475
    - long+hung 的 gap/nogap 變體全面統一成 gap_200um / no_gap
    (data/db/apdl-sim/geom/IGES + ~60 MATLAB VARIANT + fit.mat + RESULTS_MAP + README)，刪冗餘、釋 ~30GB
    - 新增規則：gap-nogap 資料夾只准 gap_200um + no_gap、要創先問
    [D_pole.SLDPRT, Full_Assembly.STEP, Geom_WithCoil.iges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]
2026-07-10 單極 fit/側視圖 + actuator 橢球圖 + 極座標磁極標記 + 圖表規則
    - 極座標 gain/iso 熱圖：沿 3 個 actuator 切面 + rim 疊磁極投影標記(hung+long)
    - 3D actuator 橢球圖(hung+long)：WP 中心 + 近 P1 tip 致動橢球 + 500µm 工作球殼
    - 單極點電荷 fit：gap 位置對(fix 無-bias) + 3 形狀 bias(no_fix，新增 fit/main_singlepole_bias)
    - 單極 magerr 直方圖(照 nb=180 規則) + bias 側視磁路圖(no_fix，tipcut zoom inset 純畫圖)
    - fix+no_fix 側視圖 3 形狀共用 colorbar(CAP=38mT，跨形狀可比)
    - bias PDF 輸出電荷位置 {ℓ̂, e_y, e_z} µm(不加 e_x=過致動)
    - 規則：figure-style 加「同類比較圖共用色階」；u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
2026-07-10 Hall-sensor 校正：實際FEM角/gap basegap重跑/B_matrix + 統一 e[µm]、小因子、emitter 整合
    上極 sensor 幾何 + gap 資料
    - build_sensor_geometry 上極錐面改用 FEM 真實傾角 upper_incline≈36.59°（非 magic-angle ψ=35.26°）
    - 新增 plot_sensor_mounting.m + sensor_mounting_{P1,P2}.png（對照 hall_sensor_full.pdf 安裝式）
    - gap_200um 資料在 basegap 網格(706k)：新 deck MT_Export_SensorLocalMesh_basegap.txt 重匯
    對齊的 sensor-local CSV → ANSYS_data/.../csv/（舊 graded CSV 差 20mm 不可用）
    - 兩包 Hall mains 重跑 gap_200um（10k 內插）→ V 乾淨、calib_D_gap_200um.mat
    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
    [MT_Dump_P1_circuit.txt, sensor_local_elems.csv, sensor_local_nodes.csv]
2026-07-11 NTU_hexapole 幾何 + model_check 交付夾改名 + STEP 交付規則
    - NTU_hexapole：平面磁極(pole.STEP) + 實心短導柱組合建模（APDL decks + OCC
    STEP helper）；組裝位置用 OCC 烘焙 pole組合.STEP transform（短導柱偏移
    +20.5,0,+11.25），交付檔 model_check/NTU_hexapole/pole_assembly.step
    - 新規則 deliver-step-for-check：交付使用者檢查一律出 STEP、不出 ANSYS IGES
    （ANSYS IGES 被 SolidWorks/OCC 讀成英吋 ×25.4，units flag 6→2 + name 2HMM 都救不了）
    - 改名 main/IGES_converted → model_check（模型檢查 STEP 交付夾）；全 repo 非-backup
    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
    [hung_full_assembly.iges, hung_full_assembly_basegap.iges, hung_hexapole_full.iges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]
2026-07-18 NTU 襯套模擬與分析 + hung 號誌修復 + matlab 依求解器分層
    - NTU full_assembly 加襯套(鐵件 μr=280)：mesh(graded) + coil1-3 模擬；
    sensor 讀值(上/下方)、導柱截面通量(z=14/15)、WP 直方圖分析；襯套分流機制
    - hung K̄_I 修復：identity map + 移除誤植的 coil_sign(全 sink 全域 negate 即可)，
    重出 model_results_R700/R300.pdf(對角全正)
    - 新增規則 pole-coil-numbering(map per-model、新 model 一律 identity+全 source)；
    charge-model-source-convention / db-folder-retention(GUI scratch 整夾刪) 等更新
    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
    [Core+yoke.SLDPRT, Core+yoke.step, Dowel pin.SLDPRT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]
2026-07-20 voltage_base: 組合電流相對誤差直方圖 + P1 sensor 偏移 3D 示意圖
    - plot_combo_region_hist.m: 50/50/100 組電流的相對 RMS 誤差直方圖(mean+CV legend)
    - plot_sensor_lateral_offset_3d.m: P1 側向/縱向/shank a=18 偏移 3D 示意(圖規則變體 A)
    - plot_sensor_mounting.m: 修硬寫路徑漏 APDL bug + λ1 標註改只顯示 4.572 mm
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2026-07-30 docs(claude): main/CLAUDE.md 綜合權威版 + FEM_sim/CLAUDE.md 指向 main
    - main/CLAUDE.md 擴為活躍工作區完整綱要(鐵則 / hexapole 約束 / APDL rules /
    繪圖規則 / prohibitions / notation / 資料夾地圖 / resolver / Quick Triggers 索引)
    - FEM_sim/CLAUDE.md 頂部加指標:main/ 為活躍權威、本檔為容器 + backup/ 樹來源;
    跨設計約束兩邊鏡像、改一處要同步
    - 慣例:新 session 開在 magnetic_sim/ANSYS/main/(cwd 往上載齊 CLAUDE.md + rules)
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2026-07-30 figures(section3a): P1&P2 側視磁路圖 + voltage R-sweep + figure-style 規則
    - plot_p1p2_poles_3d.m:P1&P2 y=0 側視磁路(coil1 激發、R=7mm 球內、turbo|B|)
    + 磁極輪廓 + sensor + n+ + WP 十字 + colorbar;比照 plot_circuit_side 標準
    - plot_ell_gV_vs_R.m:voltage_base ℓ̂/ᴮĝ_V vs R 趨勢(fix/bias)
    - figure-style.md:新增「|B| colorbar 標準樣式」「刻度間距等距」(本次 2026-07-29);
    一併帶入前次未 commit 的「n+ 自畫箭頭」「3D 磁路箭頭」(2026-07-28)
2026-07-30 Maxwell 校正管線接通 + Section2_E 圖表定案 + e/l_hat 輸出
    Maxwell（新求解器分支，首次跑通）
    - 新增 config/long2016_hexapole_halfcut/tip40um/mt_constants.m：幾何與 APDL 版逐行等價，
    三處 Maxwell 專屬 —— s_source 全 +1（.fld 已 all-source，不翻號）、apdl_to_paper_idx
    identity（B_p<k> = 論文極 P<k>）、.fld 路由（fld_dir/fld_files）
    - main.m 改呼叫 extract_maxwell_data（原沿用 APDL 版的 extract_ansys_data）
    - R150 current 結果（single + eighteen）已產出；K̄_I 對角占優、全正、K̄(1,1)=5/6 三項判準通過，
    RMSPE 3.16% → 0.31%，與 APDL 同樣呈現「fix 上下極落差為位置受限假象」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
    [ASSEM_The_Whole_Setup.STEP, full_assembly_coil.SLDPRT, full_assembly_coil.STEP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]
2026-07-31 hung R500（原始設計）重建 + Maxwell voltage 雙資料接線
    hung_hexapole R500 —— 補齊缺失的原始設計變體（R_sphere=0.5mm、tip-to-tip 1mm）
    - MT_Mesh_Graded.txt：/CWD 由 db/geom/mesh_graded 改指 db/mesh/mesh_graded_R500
    （db-folder-retention：mesh-only 產物一律進 db/mesh/）。R_sphere=0.5*MM 未動 ——
    純版 deck 的原始值就是原始設計，R300/R700 只是它 sed 改 R_sphere 的產物
    - 產出（gitignored）：mesh 560,277 節點/3.35M 元素、六顆 coil 解 bfield_all 均 560,261 行
    （完全一致，解除舊 no_gap 的跨 coil 網格不一致 crash）、single 校正 ℓ̂=887.7µm
    ĝ_I=9.2948 mT/A RMSPE 2.58%，K̄_I 四項判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
2026-08-03 paper figs(Section2_E/3_A/4_C) + tick/font rules + Maxwell voltage pipeline
    - circuit_side: 左右對調(P2|P1) + 新增 DUAL 雙電荷圖(bias粉/fix深藍 + x_a 虛線軸、含WP中心、右圖內縮對齊左圖)
    - err_hist / overlay: 軸標改 Residual (mT)
    - plot_ref_planes_3d: 新 Section4_C(150µm 殼 + 3 actuator 參考面, mm/奇數 tick)
    - plot_p1p2_poles_3d: Maxwell .fld 側視 + colorbar 版面修正
    - npts_cost_vs_R: Maxwell 版 + 等距奇數 tick(不擠/不留白)
    - Maxwell pipeline: voltage 校正(solve_voltage/build_V_matrix/emit) + calib .mat
    - rules(figure-style): tick 等距/奇數/兩端留白不過大/不太擠；字體維持 Helvetica(CM 已否決)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
2026-08-04 向量位交叉測試 + Section3_A sensor 貼附面比較 + 圖檔名規則改版
    APDL 向量位（vector potential）交叉測試——查 APDL vs Maxwell WP 場差 11~14%
    - 新增 mesh/MT_Mesh_VP.txt（SOLID237 edge element + coil1 實體 + MAT_CU）與 sim/vp/MT_Sim_VP.txt
    （BFE,,JS 方位向源電流、D,ALL,AZ,0、POST 格式與 graded 逐字相同）
    - mesh deck 參數化出 SMRT_LVL 旗標（8=定案 / 6=加密對照）；兩支 deck 目前指向 vp6 變體
    - 結果：smrt8 11.6459 → smrt6 11.2535 mT（純量位 8.8218、Maxwell 10.2002）
    → 「鋼件網格太粗」降級為次要因素（鋼件元素 1.9× 只回收 −3.4%），量級未定案
    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
    [long2016_hexapole_vp_coil1.iges]
2026-08-07 規則與繪圖腳本清理 + standard/coil1 補齊 + sensor 貼附面量化
    .claude/rules 清理（28 → 21 條）
    - 刪 7 條非活躍：comsol-livelink / read-rules-first / main-workspace / iges-model-id /
    main-workflows / hexapole-build / hung-docs。前三條的目標（main/comsol、mph、semulator、
    IGES/、analysis/、MATLAB_data/）已全部不存在，後四條內容指向已刪的 topic
    - know-how 未遺失，轉接到仍存在的位置：產物落點 → main/CLAUDE.md 架構地圖；SOP 觸發 →
    doc/workflows/README.md；COMSOL 連線 → doc/workflows/comsol-livelink.md（SOP 全文仍在）；
    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
    [sensor_refine_p1p2.iges]
2026-08-08 sensor 幾何收斂成單一來源 + CAD 實測錐體 + 全面脫離 backup
    從 CAD STEP 實測發現舊的 sensor 貼附幾何有系統性誤差，據此重建並把 11 份
    重複的幾何副本收斂成一支共用函式。
    幾何修正（CAD STEP 實測，六根極一致）
    - 錐面與 40um 倒圓球的切點在軸向 0.03216mm（不是 0.04）、半徑 0.0394mm；
    反推 r_f = 0.0402mm ⇒ 倒圓確為 40um，但切點落在球面 90deg-beta 處而非赤道。
    - 舊構法沿名目錐面母線推進、錨在理想極尖 → 貼附點埋進鋼裡，對真實錐面的
    垂距只有 0.3635mm（下極）/ 0.4012mm（上極），而非設定的 0.41mm。
    - 新構法 pos = T + s_ax*e2 + R(s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
2026-08-10 voltage 變體全數重跑新 sensor 幾何 + k22 約束參數化 + README 重寫
    補完 2026-08-08 sensor 貼附幾何修正遺留的未重跑項目。
    ## voltage 變體重跑（5 個）
    Maxwell single / soff6mm / k22_0p8340、APDL graded eighteen + single。
    自我檢查：l_hat 與 G 與舊值逐位元相同（電荷擬合只吃 WP 場、與 sensor 無關），
    只有 V / g_V 變動，一致 +3.4~3.8%：
    Maxwell single 6.2206e-3 -> 6.4390e-3 mT/mV
    Maxwell soff6mm 8.3032e-3 -> 8.5843e-3
    Maxwell k22 7.1565e-3 -> 7.4010e-3
    APDL eighteen 7.1466e-3 -> 7.4134e-3
    APDL single 6.1279e-3 -> 6.3576e-3
    k22 規則檢查通過：max|G_voltage - G_current| = 0、兩邊 RM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
2026-08-14 移除尖端安全球 + 十八參數殘差直方圖 + 釐清收斂點 N_c
    - filter_iron_nodes: safety_r 預設 100µm → 0（Maxwell 與 APDL 兩份同步）。
    極尖在 500µm，100µm 安全球往內吃到 400µm，把 R>400 的取樣球挖出六個洞
    （實測 R=400 排除 0、R=420 排除 70、R=500 排除 1452 = 2.23%），而那些節點
    是空氣不是鐵 —— 錐體包絡本身已涵蓋鐵件。改後 R=500 只剩 10 個真落在錐內
    的節點被排除，排除節點最小半徑由 402µm 回到 487µm。
    ⚠ R≥420 的 R-sweep 快取與圖需重跑；R≤400 的一切結果完全不受影響。
    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
    [0.46mm_20um.SLDPRT, 0.46mm_baseline.SLDPRT, 0.46mm_baseline_V10.SLDPRT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]
2026-08-14 擬合誤差改用 NMAE + sensor 幾何起算點改紅點 + zhi-Peng STEP 去螺紋去板
    - 擬合誤差指標 RMSPE -> NMAE（Σ|ε|/Σ|b|·100）。改 8 支（Maxwell 與 APDL 各
    solve_current/solve_voltage/main/emit_results）；RMSPE 仍算、只留 .mat 追溯。
    既有 23 份 PDF 全數回填：.mat 沒存 P/Bstack，改由 .mat 內的設定重建取樣點、
    再以存著的 l_hat/e/Fmap/V 呼叫原 solve_* 取殘差（只重算誤差、不重跑擬合）。
    每份都以「RMSPE 與 .mat 逐位相同」驗證（舊檔無 RMSPE 者改比 K̄_I），22 份成功、
    0 份失敗。唯一未完成＝voltage_tip400um（該 config 的 R_act 過不了正交性斷言，
    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
    [zhi_peng_hexapole.STEP, zhi_peng_hexapole_V2.SLDPRT, zhi_peng_hexapole_V2_split.STEP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]
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2026-08-17 db/ 收斂成 mesh + sim 兩層，deck 路徑與 IGES 落點同步
    依新規則 ansys-db-cleanup 實際執行三個 model 的 db/ 整理，並修正所有受影響的 deck 路徑。
    【磁碟】釋出 2.63 GB、保住 27.8 GB 網格孤本
    - 19 顆錯放在 db/geom/ 的網格 db 搬進 db/mesh/（保留 singlepole 的四層子夾結構）
    - geom/mesh_graded/mesh_graded.db 與 mesh/graded/ 完整 MD5 相同 → 刪重複（1.49 GB）
    - db/geom/ 三個 model 整層移除（剩餘皆為 4-22 MB 純幾何 + GUI scratch）
    - 副產物 131 檔：8 顆 sim_vp* worker .rmg、.esav/.full/.dbe、per-worker log
    - 保留 75 顆主 .rmg / 103 顆 .db / 95 個主 log，殘留掃描為 0
    【deck】98 處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
    [hung_full_assembly_R300.iges, hung_full_assembly_R700.iges, long2016_hexapole_gap_calibrate.iges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]
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2026-08-23 文件與簡報搬家：doc/ -> reference/、figures/*.pptx -> figures/doc/
    兩樁純搬移，一起進以免中間狀態出現檔案憑空消失。
    (1) doc/ -> reference/（整樹改名）
    charge_model_fitting / workflows / Solve_B_matrix / ur_iteration /
    error_definition / Force_model_fitting / Unit Reference Sheet /
    effective_permeability / Amplifier gain / List of figures 全數搬過去。
    順帶新增 sensor_placement_geometry（Sensor 貼附幾何的 LaTeX 推導 + PDF）
    與 literature（Frequency-Dependence of Relative Permeability 論文）。
    (2) figures/ 根目錄的簡報與文件 -> figures/doc/
    A Lumped.docx、Paper_fig_V1~V6.pptx、Zhi-Peng CAD Model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
2026-08-23 zhi_peng 加 R500 幾何變體，config 依幾何拆成 R500 / R594
    志鵬平面六極原本只有一顆 594 µm 的設計，現在多一顆 R_norm = 500 µm 的版本，
    兩者的 .fld 也分別匯出到 D:\Maxwell_sim\Zhi_peng\export\{R500,R594}。因此把
    原本 flat 的 config/zhi_peng/mt_constants.m 拆成兩個幾何變體子夾，照
    long2016 的 tip40um / tip400um 既定樣式（model_config(model, geom) 直接吃）。
    R500 R_norm 500 µm 名目（CAD 實測 499.905）、極板總厚 577.35 µm
    舌片徑向 極尖 -> 15 mm（接上矩形塊）
    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
    [zhi_peng_R500.SLDPRT, zhi_peng_R500.STEP, zhi_peng_R500_100um_gap.STEP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]
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2026-08-23 論文圖與快取更新、清掉被取代的舊圖與 IGES
    先前 session 產出的圖與快取，加上隨之作廢的舊檔。
    圖（Section4_C 為主）：
    極座標圖依新規則重排 —— xaya 與 xaza 併成一張並排、共用色階 ->
    gain/iso_polar_xaya_xaza_maxwell_zhi_peng 取代舊的 xaya / xaza 兩張
    sigma / gain / iso 直方圖補齊 R150 與 R500 兩個評估半徑、long2016 與
    zhi_peng 兩個模型；bin 寬依新規則調整（kappa 0.0031 -> 0.011）
    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
    [sensor_refine_p1p2.iges, singlepole_filled_gap_x42a150.iges, singlepole_filled_gap_x42p5.iges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]
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2026-08-24 main.m：修好 GRID_NRPT 非 auto 時必炸的 assert，per-run 旋鈕切到 zhi_peng gap
    Bug：收斂迴圈後那行寫成
    assert(ws_hit, 'workspace：...(%d,%d,%d)', CONV_NDMAX, LADW(end,:));
    MATLAB 會**先求值全部引數**再呼叫 assert，所以 GRID_NRPT=[] （全格點）或
    手動三元組時（不迴圈、LADW 為空）LADW(end,:) 必定丟
    「Index in position 1 is invalid」。也就是 2026-08-23 把收斂迴圈搬進 main.m
    之後，[] 與手動三元組這兩條路從來沒被跑通過 —— 三態旗標實際上只有 'auto'
    能用。改成只在真的沒收斂時才去索引 LADW。
    驗證：修好後跑 zhi_peng / R500 / maxwell_gap / single / GRID_NRPT=[] 成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
2026-08-24 新規則 short-names：檔名一律要短，升格為全 repo 通則
    使用者拍板：「這個專案所有檔名都不要太長，簡單就好」。原本這件事散在
    results-pdf-only.md（結果 PDF 由 38 字元縮到 17）與 memory short-filenames
    （IGES / APDL 命名）裡、各綁各的資料夾；現在抽成一條通則。
    規則內容：
    1. 路徑已經講過的事，檔名不要再講一次（model / 分支 / single-eighteen
    由資料夾表達）
    2. 變體後綴 3-6 字元，縮寫要在註解或 config 寫明
    3. 只留「會用來區分」的欄位
    4. 參數值用緊湊寫法（_R150、_soff3mm、小數點寫 p）
    5. 資料夾名同此
    6. 變體超過 ~5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
2026-08-24 極座標圖：檔名補 variant 後綴，colorbar 改「資料覆蓋最大化」
    plot_svd_polar 的輸出檔名原本只帶 model，不帶 variant -> 同一個 model 有多版場
    （zhi_peng 的 maxwell / maxwell_split / maxwell_gap）時會互相覆蓋。補上後綴，
    非預設 variant 才加，並照 short-names 剝掉整棵樹都一樣的分支名 'maxwell'
    （maxwell_gap -> _gap、maxwell_split -> _split）。
    cbar_ticks 的判準由「區間數最接近 4」改成「在 3~6 個乾淨區間中取跨度最小
    （= 資料覆蓋最大）」，同分取整數刻度。起因：舊判準只管刻度好不好看、不管
    浪費多少色階 —— zhi_peng gap 的資料 19.90~30.83 被撐成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
2026-09-24 力模型校正接上真實量測：FSRC='sph' 模式與收斂階梯
    Force/Maxwell/main/main.m 加一個量測來源開關，原本的自洽模式一行未動：
    'selfcheck' f_m 由 flux 校正合成（有真值，維持 PASS/FAIL 表）
    'sph' f_m = (1/2)*mgB*grad(b.b)，b.b 取自球諧場模型（無真值）
    sph 這條走 flux 既有載入器取 r<=R 的節點（同一批點、同濾鐵、同 s_source），
    球諧只擬一次，21 組激發（6 單極 + 15 配對）靠 c(I)=sum_k I_k c_k 疊加取得，
    不重擬合。收斂判準逐字沿用 flux 的兩段式 judge（TOL_S=0.01%/KS=20、
    TOL_C=0.2%/KC=10、KOUT=1，l_hat 與 F g 都要收斂、取較晚者），不加物理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
2026-10-05 問題文件移到 reference/Question；Flux/Maxwell utils 依模型分夾（補齊路徑修正）
    - noise_analysis.md、force_metrics.md 由 charge_model_fitting/general 移到 reference/Question，新增 Question/README.md
    - utils/{scripts,data}/long2016_hexapole_halfcut/：補上 80fb042 只搬未改的路徑修正，與 eps_shell / sph_rms 腳本及資料
    - rms_ladder.m 一併納入先前未 commit 的 R 掃描模式（產 rms_ladder_R.mat）
    - plot/long2016_hexapole_halfcut/current 三支繪圖腳本改讀新位置
    - CLAUDE.md、README.md、calibration-shared-structure、plot-scripts-pure 同步改為 utils/{scripts,data}/<model>/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
2026-10-06 問題：對極單一激發、中心取樣時 cost 曲線在 ℓ̂ 大側變平（10.6 簡報第 3、4 頁）
    - reference/Question/cost_flat_pair.md：觀察（志鵬對極三維輪廓一/兩激發；NTU 一維單極 vs 對極中心取樣）、問題、可考慮方向、相關檔案；Question/README 加一列
    - NTU 一維模型：取樣、擬合、profile cost、雜訊蒙地卡羅的腳本與資料（utils/{scripts,data}/NTU_hexapole），繪圖腳本（plot/NTU_hexapole/current）與圖（sampling、b_axis 殘差、cost_b、noise_hist，含 _c500 中心取樣版）
    - 志鵬對極：一維擬合與 y=0 切面（utils/{scripts,data}/zhi_peng）、取樣與場圖腳本（plot/zhi_peng/pair_sa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
2026-10-24 Force/Maxwell：T1 接力標籤角點 4 組改由最佳鄰點重解（long2016）
    - chain.m：FIX=n 把力誤差最大的 n 組未收斂點從每個向內鄰點各重解一次、取力誤差最小者（-> _fix.mat）；
    APPLY=true 寫回接力標籤檔並重寫 _err.mat
    - 角點 (45,45,-45) µm 的 4 組：力誤差 0.40/0.38/0.15/0.15% -> 0.054/0.033/~0/~0%（原本用的 z 鄰點最差）
    - chain_d15：未收斂 64 -> 62 組，力誤差最大 0.40% -> 0.0895%
2026-10-24 Force/Maxwell：T1 角點 4 組改為「不換支、誤差最小」的鄰點重解（long2016）
    - chain.m：FIX 的挑選加上換支條件，重解電流與出發鄰點電流 cos < CMIN（0.9）視為換支、不採用；
    在不換支的解中取力誤差最小者，全部換支則保留原解
    - 角點 (45,45,-45) µm：(10,190) x 鄰點 0.054%、(10,260) y 鄰點 0.033%、
    (75,230) y 鄰點 0.015%、(75,220) x 鄰點 0.019%（後兩組排除 cos 0.82 的換支解）
    - chain_d15：未收斂 64 組，力誤差最大 0.0895%
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
